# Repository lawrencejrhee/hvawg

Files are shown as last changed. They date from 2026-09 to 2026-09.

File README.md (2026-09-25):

# High Voltage Arbitrary Waveform Generator

This is the first draft iteration of a modular arbitrary waveform generator intended to generate possibly tens of separate ±100V 1MHz signals for small capacitive loads, e.g., electrostatic actuators or ion traps.

WARNING: THIS BOARD IS DANGEROUS. IT USES SOMEWHAT HIGH VOLTAGES AT SOMEWHAT HIGH POWER. DO NOT BUILD, TEST, OR USE WITHOUT BOTH CAUTION AND KNOWING WHAT YOU ARE DOING. No guarantees or warranty or support is provided, etc.

3D render of PCB

Specifications:
- serial data input at 3.3V or 5V up to maybe 100MHz, intended to be driven by FPGA
- 8-bit onboard DAC (with +/-1V output) (ENOB not measured but probably closer to 6 bits)
- amplifier with 100x gain gives outputs ±150V
- maximum output frequency is in the 100kHz range varying with load and voltage
- maximum designed load is tens of picofarads and megaohms of resistance
- up to four boards can be daisy-chained
- quiescent power consumption around 5 to 10W (b/c inefficient class A output stage)
- efficiency ≈1% (b/c inefficient class A output stage in open loop control)
- boards cost about $20 each and use only standard off-the-shelf parts

Measured frequency response:

(generated by feeding external signal into on-board amplifier bypassing DAC)

frequency response curve

## Circuit Design

This circuit was made with the following constraints in mind:
- This is primarily intended to drive small capacitive loads, on the order of tens of picofarads with maybe megaohms of resistance. Note that oscilloscope input impedances are also about this much.
- Arbitrary waveform outputs between -100V and +100V and up to 1MHz. Either of those constraints is easy; together they are nontrivial. The ADHV4702 opamp can reach those voltages but only up to about 20kHz, for example.
- In order to have multiple outputs, multiple boards should be able to be daisy chained together. The final design allows up to four boards to be daisy chained and driven off a single 4-wire serial connection (three signals plus GND), for an average of 0.75 input signals per board, to drive as many boards as possible off of a single FPGA or other controller.
- Low cost. If tens of these boards are required for an application, each one should individually be cheap. This resulted in, e.g., five separate power supply inputs. The final part cost per board is around $20. Note a 2-layer PCB was used to decrease manufacturing time for external reasons; switching a 4-layer PCB or better is probably a good idea to allow better EMI mitigation techniques.
- DAC accuracy was not a priority. The original application needed less than 6 bits of resolution.
- Mass production. The circuit should not rely on manually matched transistors for a carefully-balanced amplifier. Instead, the output uses current mirrors that are cheaply implemented with off-the-shelf silicon power MOSFETs and don't require closed loop control on the output (which is not easily achieved at 1MHz at those voltages due to transistor switching time). (There is still manual tuning of amplifier gain and bias in order to minimize cost and accuracy, but this only has to be done once per board.)
- Robustness. The output can probably survive a short-circuit (untested).

The amplifier looks something like the following:

frequency response curve

### Alternatives

Previous but insufficient approaches to similar problems include:
- Using a high-voltage op-amp, e.g., the ADHV4702 <https://www.analog.com/en/products/adhv4702-1.html>. This can achieve the +/-100V range but only up to a bit over 20kHz.
- Resonant circuits. Common in ion traps and particle accelerators, but only generate a single specific frequency.
- Discrete amplifiers of assorted topologies, e.g., <https://doi.org/10.1063/1.1988272> or <https://doi.org/10.1063/1.3622750> or <https://www.radiolocman.com/shem/schematics.html?di=637101>. Note also <https://www.falco-systems.com/High_voltage_amplifier_WMA-300.html>. Commonly used for piezoelectric actuator drives, ultrasound, MEMS, or ion traps. These amplifiers achieve the required voltage and frequency specifications but are expensive and/or complex and rely on obscure components.

### Power input

This board takes five power inputs (in addition to the GND connection, of course):
- +12V (1W)
- -12V (1W)
- +100V (5W)
- -100V (5W)
- 12V above the -100V negative rail (1W)

These should be turned on in the following order:
1. +12V
2. -12V
3. +100V
4. -100V
5. 12V above -100V rail

LEDs indicate when the three 12V power supplies are on.

The power supplies used for testing were Wanptek WPS series supplies (160V 2A and 30V 10A) from eBay.

The +/-100V high voltage supplies are used to drive the output and need to be capable of the full board power draw (potentially 10W each, depending on component selection and voltage output).

The +/-12V supplies are used to drive the DAC and intermediate amplifier opamps. These are not generated from the +/-100V because a linear regulator would be too lossy and a buck regulator would make the board significantly more complex and expensive.
Likewise, the low 12V supply is used to drive the output amplifier opamp, and is not generated from the other supplies for the same efficiency reason.

If more convenience is required, an external board can generate the 12V and 100V supplies however desired.

### DAC

The DAC circuit takes a serial input via the 74HC595 shift register and sends the output to a DAC0909 DAC chip.

The DAC is 8 bits. Four PCBs can be daisy-chained together (requiring 32 bits).

The DAC should theoretically operate up to about 100MHz, allowing four 8-bit daisy-chained boards to be updated at above 1MHz. This upper speed has not been tested yet and may be limited by inferior PCB routing.

The DAC protocol works (via the 74HC595) as follows:
- Input signals at 3.3V or 5V should both work.
- 4 pins are required (GND, store_clock, shift_clock, and serial_in).
- First, data is sent in via serial_in at each rising edge of the shift_clock.
- Next, when store_clock is brought high, the current state of the data is saved and sent to the DAC.

This should work with any 74HC595 code, e.g., many Arduino libraries.

### Level shifter

The level shifter circuit accepts an input +/-1V analog signal, translates this into a current, and sends the result to the negative high voltage rail, where it is converted back into an analog voltage to drive the output opamp.

The level shifter can be disconnected from the DAC via jumper JP3 in order to input an external analog signal (e.g., from a low-voltage waveform generator) for testing purposes.

Potentiometer RV1 controls the gain of the high voltage output and should be adjusted to give a 100x amplification.

NOTE: PCBs FABBED FROM PRE-2026-09-09 DESIGN FILES HAVE AN ERROR (see "Errata" below) where the source and drain of PMOS transistor Q3 are switched. If this is not fixed during assembly, when the high voltage low rail is turned on, significant current will flow through R17, which will burn out due to excessive power draw. The design files were corrected on 2026-09-09 (schematic pin mapping + copper reroute, DRC/ERC/netlist verified); boards fabbed from the corrected files take Q3 with straight legs. The exported gerbers under jlcpcb/ are generated from the V2 design revision, which includes this fix.

### High side monitor circuit

This subcircuit provides compensation such that the final high-voltage output is independent of the high voltage supply level (i.e., high voltage inputs of +50V, +100V, and +150V should not affect a 50Vpp output signal).

Potentiometer RV2 controls the DC bias of the output and should be adjusted to center the output at GND = 0V.

Resistor R12=110kohm dissipating up to 200mW was specifically chosen to minimize power draw while also maximizing the voltage/current at the input to opamp U8A (which has nonzero input offset current).

### Output amplifier

This circuit takes an input voltage signal near the negative rail (from the level shifter) and converts this into a current signal through Q1 and R21, which form a class-A amplifier to generate the final high-voltage output. The output voltage is determined by the voltage drop of R21 with the given current.

R21 and Q1, as a class-A amplifier, form a resistive divider between the high voltage power rails, and dissipate a large (10W) current even in their quiescent state in order to drive loads with reasonable accuracy. This means they generate significant heat.

R21 was chosen at 10k as a reasonable compromise between quiescent power draw and load drive ability. R21 can be replaced with a 5kohm power resistor to draw more current but double the output load capacity.

### Output

The final output from R21 and Q1 can be connected to any one of outputs 1 through 4 via jumpers JP8 through JP11.

Four daisy-chained boards can thus be attached to separate outputs.

## Assembly and Testing

### Part choice notes

- All SMD parts are from JLCPCB and specifically chosen from parts with reliable high stock.

- Hand-soldered components were added manually afterward (not through JLCPCB) to reduce order lead time.

### Manufacturing notes

These boards were designed in KiCad and ordered from JLCPCB with help from the excellent kicad-jlc-pcb tools plugin <https://github.com/bouni/kicad-jlcpcb-tools>.

### Assembly notes

Hand assembly of the through hole components takes about 20 minutes per board.

Boards fabbed from pre-2026-09-09 design files: be sure to bend the legs of the PMOS MOSFET (Q3) to switch its source and drain to fix a board error (see "Errata" section below). Boards fabbed from the corrected design files (2026-09-09 or later) install Q3 normally with straight legs — verify which revision a bare board is before assembly.

Header pins are ordered in lenths of 18 to reduce costs. These should be manually cut to size (or ordered in the right size to begin with).

The power resistor R21 needs spare wires soldered on to fit the PCB footprint. The resistor hangs off the edge of the board so it can be bolted to a heatsink. It's possible these spare wires increase EMI emissions. Future board iterations could switch to a TO-220 package power resistor, matching NMOS transistor Q1, which is also at the edge of the board for easy heatsink mounting.

V2 boards (the current design files) mount R21 on the board instead. It is a TO-220 power resistor (LTO050F10001JTE3) laid flat in a small bolt-on heatsink (Wakefield 272-AB), which is screwed to the board and tied to GND. Q1 still goes on a heatsink bar along the board edge. Its tab is at the output voltage, so it needs an insulating pad (Sil-Pad K-10) and a shoulder washer (Keystone 3049). V2 boards also change the connector pinouts, the trimpots (1kohm, wired as rheostats; RV1 now centers the output and RV2 sets the gain) and the power input (J9, a pluggable 8-pin terminal block). On V2 boards the 5kohm R21 option (see Output amplifier) would double R21's dissipation, beyond what the on-board heatsink is sized for. See BRINGUP-V2.md for assembly and bringup, and V2-SUMMARY.md for the full list of changes.

### Bringup notes

The notes below are for V1 boards. V2 boards use BRINGUP-V2.md.

After the board is assembled, the following bringup/test strategy seems to work well:

- Start with jumpers JP3, JP4, and JP6 disconnected. Connect one of JP8, JP9, JP10, JP11 to choose output.
- Test DAC. Apply +12V then -12V supply (if +12V but not -12V is applied too long, DAC may heat up). Confirm LEDs light up. Add DAC input signal. Use thermal camera to confirm no major hot spots (NE5532 opamps at 35°C, LEDs at 32°C, not much else).
- Confirm DAC output is good (TP2/JP3 via oscilloscope). Full scale output is around 2.8Vpp.
- Test high voltage monitor circuit. Attach +120V supply, confirm high voltage monitor output (TP3 via multimeter) is stable and good and in the 1 to 3V range. R12 should rise in temperature (maybe 36°C) due to its 200mW power dissipation.
- Turn off power supplies and add jumpers JP3, JP6.
- Test level shifter. Apply +12V, -12V, +120V, and -120V. Confirm temperatures good (no significant change from before).
- Confirm DAC and monitor outputs remain good.
- Confirm level shifter output is sine wave (measure JP4 oscilloscope with AC coupling).
- Turn supplies off again, add jumper JP4.
- Test final output stage. Turn supplies on, including +12V on negative rail this time (additional LED should come on).
- Confirm only thermal change is output resistor and MOSFET heating to maybe 60-80°C (if supplies are +/-120V).
- Confirm final board output (measured at TP5, output port, or resistor lead via DC-coupled multimeter) is expected signal. Might be DC shifted and cut off at high/low rail.
- Adjust RV2 to center output wave at 0V.
- Adjust RV1 to set gain to get about +/-100V output. Can set to +/-128V full-scale output so that a 1 bit input change results in 1V output change.

### SMD components (JLCPCB)

| Part no. | QTY | Cost | JLC type | Note | URL |
|---|-----|---|---|---|---|
| 74HC595D,118 | 1 | 0.10 | basic | shift register | https://jlcpcb.com/partdetail/Nexperia-74HC595D118/C5947 |
| DAC0808LCMX/NOPB  | 1 | 1.80 | extended | dac | https://jlcpcb.com/partdetail/TexasInstruments-DAC0808LCMXNOPB/C132006 |
| NE5532DR | 2 | 0.15 | basic | opamp | https://jlcpcb.com/partdetail/TexasInstruments-NE5532DR/C7426 |
| LM8261M5X/NOPB | 2 | 2.12 | extended | opamp | https://jlcpcb.com/partdetail/TexasInstruments-LM8261M5XNOPB/C7968 |
| L78M05ABDT-TR | 1 | 0.13 | basic | 5V regulator | https://jlcpcb.com/partdetail/Stmicroelectronics-L78M05ABDTTR/C58069 |
| KT-0603W | 3 | 0.01 | basic | white 0603 LED | https://jlcpcb.com/partdetail/Hubei_KentoElec-KT0603W/C2290 |
| RT0402BRE072K74L  |  12 | 0.02 | extended | 2.74kohm 0402 0.1% 62.5mW | https://jlcpcb.com/partdetail/Yageo-RT0402BRE072K74L/C705647 |
| WR20X750JTL | 1 | 0.02 | extended | 75ohm 2010 200V | https://jlcpcb.com/partdetail/Walsin_TechCorp-WR20X750JTL/C172257 |
| 1206W4F1004T5E | 4 | 0.01 | basic | 1Mohm 1206 200V 250mW | https://jlcpcb.com/partdetail/18615-1206W4F1004T5E/C17927 |
| UD2D4R7M0810 | 2 | 0.08 | extended | 4.7uF 200V SMD | https://jlcpcb.com/partdetail/HonorElec-UD2D4R7M0810/C88701 |
| CC0603KRX7R9BB104 |  12 | 0.01 | basic | 100nF 0603 50V | https://jlcpcb.com/partdetail/Yageo-CC0603KRX7R9BB104/C14663 |
| CL31A106KBHNNNE |  13 | 0.03 | basic | 10uF 1206 50V | https://jlcpcb.com/partdetail/14236-CL31A106KBHNNNE/C13585 |
| 2010W2J0114T4S | 1 | 0.01 | extended | 110kohm 2010 200V 500mW | https://jlcpcb.com/partdetail/21062-2010W2J0114T4S/C20351 |
| CRGP2512F22K | 1 | 0.41 | unknown  | 22kohm 2512 500V 2W (V2)  | https://www.lcsc.com/datasheet/C2076055.pdf |
| CL31B106KAHNNNE | 1 | 0.19 | extended | 10uF 1206 25V X7R (V2) | https://jlcpcb.com/partdetail/C14860 |

The last two rows are V2 parts: CRGP2512F22K is R30 and CL31B106KAHNNNE is C24. V2 boards also use D4, D5, R26-R29 and R31 (see the schematic). They take 12 of CL31A106KBHNNNE instead of 13, because C24 sits next to the R21 heatsink and must be the X7R part (rated to 125°C, while CL31A106KBHNNNE is X5R and rated to 85°C).

### Through-hole components (manually added afterward)

| Part no. | QTY | Cost  | Note | URL |
|---|-----|---|---|---|
| 3296Y-1-472LF  | 2 | $1.3  | 4.7kohm trimpot | https://www.digikey.com/en/products/detail/bourns-inc/3296Y-1-472LF/2536016 |
| IRF9610PBF | 1 | $1.1  | PMOS power FET | https://www.digikey.com/en/products/detail/vishay-siliconix/IRF9610PBF/811768 |
| IRF730PBF | 1 | $1.1  | NMOS power FET | https://www.digikey.com/en/products/detail/vishay-siliconix/IRF730PBF/811793 |
| QPC02SXGN-RC | 4 | $0.04 | jumper | https://www.digikey.com/en/products/detail/sullins-connector-solutions/QPC02SXGN-RC/2618262 |
| THS2510KJ | 1 | $2.5  | 10kohm power resistor | https://www.digikey.com/en/products/detail/te-connectivity-passive-product/THS2510KJ/2366983  |
| PREC018SABN-RC | 3 | $0.25 | 18-pin male header | https://www.digikey.com/en/products/detail/sullins-connector-solutions/PREC018SABN-RC/2775036 |
| PPPC181LGBN-RC | 3 | $0.82 | 18-pin female header  | https://www.digikey.com/en/products/detail/sullins-connector-solutions/PPPC181LGBN-RC/775951  |
| 3296Y-1-102LF  | 2 | - | 1kohm trimpot (V2) | https://www.bourns.com/docs/Product-Datasheets/3296.pdf |
| LTO050F10001JTE3 | 1 | $5.1  | 10kohm TO-220 (V2) | https://www.vishay.com/docs/50050/lto50.pdf |
| 272-AB | 1 | $0.79 | TO-220 heatsink (V2)  | https://www.digikey.com/en/products/detail/wakefield-vette/272-AB/345-1043-ND/340341 |
| 1844278 | 1 | $3.26 | J9 header (V2) | https://www.phoenixcontact.com/en-us/products/pcb-header-mc-15-8-g-35-1844278 |
| 1840421 | 1 | $9.32 | J9 plug (V2) | https://www.phoenixcontact.com/en-us/products/pcb-plug-mc-15-8-st-35-1840421 |

V2 boards use the 1kohm trimpots and LTO050F10001JTE3 instead of the 4.7kohm trimpots and THS2510KJ. They also need two M3 screws with washers and nuts plus non-silicone thermal compound (e.g., Wakefield 126) to mount R21 and its heatsink, and a Sil-Pad K-10 and Keystone 3049 shoulder washer for Q1 (details in BRINGUP-V2.md).

## Errata and Future Improvements

Board error (FIXED in design files 2026-09-09; still applies to boards fabbed before then):
- The PMOS transistor (Q3) source and drain pins are switched on the PCB. On boards fabbed from pre-fix files, this can be fixed when hand-soldering by bending the MOSFET legs to fit the right holes. Not doing this causes excessive current through R17, burning it out, with possible additional damage to RV1.
- Design-file fix (2026-09-09): the Q_PMOS_GDS symbol pin mapping for Q3 was corrected in hvawg.kicad_sch (S=pin 3 to the RV1/U6 network, D=pin 2 to levelshift_out, matching the physical IRF9610 G-D-S pinout), the corresponding pad nets were swapped and copper rerouted in hvawg.kicad_pcb (net "Net-(Q3-D)" renamed "Net-(Q3-S)", zones refilled). Verified: netlist shows Q3 pin 2 on levelshift_out / pin 3 on Net-(Q3-S); DRC and ERC reports are identical to pre-fix baseline (no new violations, 0 unconnected). Boards fabbed from these files install Q3 with straight legs. The exported gerbers and production zip under jlcpcb/ were regenerated for this fix on 2026-09-09 (drill files verified hole-identical; copper carries the corrected nets), and again from the V2 design revision from 2026-09-23 on (each time checked against the board: DRC clean, every drill-hole change accounted for). Regenerate them after any further board change. The BOM/CPL files have not been updated for the V2 parts; regenerate them with the kicad-jlcpcb-tools plugin.
- A safe first-power check for ANY board of unknown revision: set the negative-HV supply current limit to 2 mA and ramp toward -20 V. Reaching full voltage at under ~1 mA means Q3 is correct; pinning at the 2 mA limit with the rail collapsed means the swap is active (the 2 mA ceiling keeps R17 well within its power rating either way).

EMI issue:
- I suspect this board might sometimes generate nontrivial RF noise. Qualitative tests show unshielded wires on the output (or maybe even the wires connecting the through-hole power resistor) generate an undesired signal. Thus, be very careful with board use. Future board iterations should fix this issue by, e.g., more careful PCB trace design and changing the signal output connector to a shielded RF SMA connector or similar.

Improvements:
- The first iteration used a 25W chassis-mount power resistor, which worked fine without heatsinking but needed manual wiring to the PCB. To avoid the inconvenience of having a component not directly mounted to the PCB, future iterations might consider using a TO-220 package power resistor and heatsinking instead (e.g., AP836 10K J, https://www.digikey.com/en/products/detail/ohmite/AP836-10K-J/5878547 ).
- A 2-layer PCB was used to decrease manufacturing time for external reasons; switching a 4-layer PCB or better is probably a good idea to allow better EMI mitigation techniques.

## Images

### 3D render

3D render of PCB

### Assembled PCBs

Two assembled PCBs

### Thermal testing

Note the hottest parts of the circuit are the power resistor and MOSFET near the output, as expected.

Two assembled PCBs

### Frequency response testing

An external function generator was used to generate test waveforms by disconnecting the DAC via jumper JP3.

frequency response test setup

### Daisychain test

Two boards generating 200Vpp 1kHz waves

### PCB frame concept

Heatsinks, external wires, and control board not included. Note a large flat heatsink is easy to add along the output power resistors and MOSFETs.

PCB frame concept

### EMI Issue

Several-foot-long unshielded wires connected to the output and a capacitive load interfere with the signal generator. Note the waveform on the oscilloscope only shows half a sinusoid; the lower half was somehow blocked. The test was immediately stopped.

EMI discovery

Using a shielded cable reduced interference, but that's still not a perfect sinusoid on the oscilloscope. Recommendation: improve PCB to minimize external wires and other possible EMI sources and use a proper RF SMA connector for the output.

lower EMI with shielded cable

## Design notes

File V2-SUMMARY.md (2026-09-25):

# HVAWG V2: status, simulation results, decisions and remaining work

For: Yichen. Date: 2026-09-24. Status: the V2 design files and gerbers were committed on 2026-09-25 (61018b9).

TL;DR: Your items 1-9 are implemented and verified in the KiCad files, and the JLCPCB gerbers are regenerated from the final board. V2 also includes:
- a high-voltage safety revision (sections 2.6 and 2.7)
- R21 moved onto the board and laid flat in a Wakefield 272-AB heatsink (section 2.8)
- a re-layout: a plain 207 x 58.8mm rectangle with J9 in a small edge notch, new silkscreen, and U4B/U8B tied off (section 2.9)
- Sims 6 and 7: R21 parasitics and a coverage audit of every final value (section 2.10)
- the resolved decisions in section 3: R29 = 1Mohm, SMD test pads for TP9-TP12, J9 at 3.50mm, no BSS126, R21 flat, and R30 as a 2W 2512

LTSpice checks show the V2 values are correct as long as R19/R23 stay unpopulated.

Details below.

## 1. What was implemented

| # | Your item | Implementation | Status |
|-----|---|---|---|
| 1 | Fix the Q3 (IRF9610) S/D swap | Schematic pin map fixed, pad nets swapped, copper rerouted | Done, committed in 225dc5d |
| 2 | RV1 as a rheostat + 3.3k series | RV1 = 1k (wiper tied to pin 3), R26 = 3.3k | Done |
| 3 | RV2 as a rheostat + 820ohm series | RV2 = 1k (wiper tied to pin 3), R27 = 820 to GND | Done |
| 4 | Gate-source resistor + zener on the FETs | Q1: R28 100k + D4 BZT52C12 (K to G). Q3: R29 1Mohm (was 100k; changed per Sims 1/3/5) + D5 BZT52C12 (K to S) | Done |
| 5 | 10k between the divider tap and U8 | R30 in series with U8 pin 3. Only U8's input sits behind it. First 10k, now 22k 2W 2512 (sections 2.5, 2.7, 2.10) | Done, see the R30 finding in section 2.5 |
| 6 | Test points on the Q3/Q1 gates and sources and U7's rails | TP7/TP8 = Q3 G/S, TP9/TP10 = Q1 G/S, TP11/TP12 = -100+12V / -100V | Done. TP9-TP12 are SMD 1.5mm diameter pads 1.5-5.8mm from the pins they probe |
| 7 | TP6 after the series R; keep TP5 before it | TP5 on the amp side, TP6 on the new net output_post | Done |
| 8 | Empty pads for an R+C test load | R32 (1206) + C32 (first 0603, now 1206 pads; section 2.7), both DNP, from TP5 to GND | Done, see decision 4 in section 3 for where it attaches |
| 9 | Series output resistor on board | R31 = 4.7k (first 1206, now 2512 for voltage and fault margin; section 2.7) | Done |

The JP8-JP11 output selectors now sit on output_post, after R31.

Six existing nets were renamed automatically by KiCad because the new parts changed the alphabetical naming. Connectivity is unchanged:

| Old name | New name |
|---|---|
| Net-(Q1-G) | Net-(D4-K) |
| Net-(Q1-S) | Net-(D4-A) |
| Net-(Q3-G) | Net-(D5-A) |
| Net-(Q3-S) | Net-(D5-K) |
| Net-(JP10-A) | Net-(Q1-D) |
| Divider tap  | Net-(C14-Pad1) |

### Verification of the design files

The figures in this subsection and in section 1b are from that stage. The current board's check results are in section 2.8.

- Netlist: every item has the intended connectivity, and exactly 13 nets changed membership. All 260 of 260 pin-to-net assignments match between the schematic and the board.
- ERC: no new errors. There are actually two fewer: the unconnected RV1/RV2 pin 3 errors are gone because of the rheostat ties.
- DRC (after the connector fix in section 1b): 0 errors, 0 unconnected, 0 clearance/short errors, 0 silkscreen overlaps, 0 silkscreen over copper. What remains are pre-existing warnings only:
  - 8 silk_edge_clearance: R21/Q1 graphics, which intentionally hang past the board edge for heatsinking.
  - 37 lib_footprint_mismatch: the KiCad 9 library versions differ from the ones on the board. These were intentionally not "updated", to avoid changing pads on parts that work.
  - 29 footprint_symbol_mismatch: exclude-from-BOM flag differences.
  - For comparison, the original design had 5 errors and 91 warnings, and the first V2 version had 5 errors and 165 warnings.
- Gerbers: regenerated and installed in jlcpcb/.
  - Every drill-hole change is accounted for (PTH holes went from 125 to 132 overall). The V2 parts added 7 new Keystone test points (TP6-TP12). The connector fix moved connector pins and TP8 and changed some vias.
  - A second export matches the installed files byte-for-byte except timestamps.

### 1b. Connector spacing fix (the 5 DRC errors)

The original design had 5 courtyard-overlap errors: the daisy-chain and power connectors sat flush against each other. Since only V2 boards will be stacked, they were spread apart by the smallest amounts that clear them:

| Part | Move | Notes |
|---|---|---|
| J1-J4, J7, J8 | none | Daisy-chain pins unchanged |
| J5 + J6 (HV daisy-chain pair) | +1.27mm in x, both identical | Every mating pair still lines up exactly |
| J9 (bench power input) | +1.27mm in y | Pinout unchanged |
| J10 (GND pin) | +1.27mm in x | |
| TP8, R31 | +0.5mm / +0.25mm in x | Moved to make room |

- Assembly note: J3+J5 and J4+J6 used to form one continuous 8-pin row, and J7+J10 a 5-pin row. Each connector now needs its own header strip.
- HV clearances improved. The closest +HV to -HV copper went from 0.47mm to 0.84mm. All rerouted copper keeps at least 0.8mm between the HV rails and at least 0.5mm from HV to anything else.
- Every pad kept its net.
- The schematic is untouched.

## 2. Findings from the simulations

The netlists are in simulations/v2/ (the logs come from running them and are not committed). There is no LTSpice model for the IRF9610 or IRF730, so datasheet-based VDMOS approximations were used. The comparisons are more trustworthy than the absolute numbers. The LM8261 uses the vendor model, unchanged.

### 2.1 Your RV1/RV2 values are correct when R19/R23 are not fitted (Sim 1)

With the op-amps enforcing their virtual shorts:
- Centered gain = (R21 / R_src) x R_load / R_RV1
- Centering requires R_RV1 = K x R_bottom / (110k + R_bottom), where K = (R21 / R_src) x R_load

| Board | K | RV1 needed to center | Result with the V2 range (3.3-4.3kohm) |
|---|---|---|---|
| R19/R23 unfitted (as built) | 10k/75 x 2.7k = 360,000  | about 3.6kohm at R_bottom = 1.11k | Centers at ±50V and ±120V, gain about 90-120 |
| R19/R23 fitted | 10k/42.9 x 96.4 = 22,500 | about 225ohm | Cannot center. Output stuck near the + rail, gain about 5-7 |

- R19 and R23 must stay DNP.
- Note on BRINGUP-V2.md: an earlier draft's Phase 3 example (96.4/R_RV1, R_RV1 = 225ohm) described the fitted configuration. The current BRINGUP-V2.md uses the as-built numbers, 2.74k and about 3.65kohm. With the final values the usable gain range is about 85-110 (from the RV2 window in section 2.10 item 3).
- Output = 100 x V_DAC, independent of the rail voltage (the monitor compensation doing its job). The usable DAC swing is therefore about ±V_TP3, roughly ±0.5V at ±50V rails. A full-scale DAC (about ±1.4V) clips at both rails, which explains the clipped outputs seen on the bench at ±50V.

### 2.2 R29 = 100k breaks rail-independence (Sims 1, 3, 5), recommend 1Mohm

R29 carries V_SG / R29, about 18-38uA depending on Q3's threshold, around Q3. That current does not scale with the rail voltage, while Q3's current does (about 137uA at ±50V, about 332uA at ±120V). So a board trimmed at one rail voltage is off-center at the other.

Output offset after trimming at one rail voltage and then running at the other:

| R29 | Q3 Vth | Trimmed at ±120V, run at ±50V | Trimmed at ±50V, run at ±120V |
|---|---|---|---|
| 100k  | -2 / -3 / -4V | +3.6 / +5.8 / +7.9V | -8.7 / -14.0 / -19.1V |
| 1Mohm | -2 / -4V | +0.2 / +0.6V | -0.5 / -1.5V |

At 100k it also degrades the level shifter (Sim 3):

| Metric | V1 (no R29/D5) | R29 = 100k | R29 = 1Mohm (+ D5) |
|---|---|---|---|
| THD at ±50V | 2.2% | 5.3% | 2.65% |
| THD at ±120V | 1.3% | 2.2% | 1.55% |
| TP4 shift | - | -77mV (about +0.1V DAC-equivalent offset) | -7.7mV |
| Usable positive DAC swing at ±50V | - | -19% | - |

- 1Mohm still holds Q3 off. Worst-case IRF9610 gate leakage (about 100nA) x 1Mohm is about 0.1V, far below |Vth| = 2-4V.
- It's a value change only. Same 0402 footprint, so the gerbers are unaffected.
- With 1Mohm, the nominal RV2 setting (R_bottom about 1.11k) centers at both rail voltages (RV1 about 3.57k).

### 2.3 D4/D5 zeners, R28, and R31 (Sims 2 and 3): fine with the IRF730

- Output stage at 100kHz (IRF730 as fitted, and STW11NM80):
  - V2 costs 0.3% of swing at TP6 with a 10pF load, and 0.9% with 20pF.
  - It adds a +0.3V offset, which the trim removes. (This is sim-stage wording. In the V2 procedure, RV1 is re-trimmed live at the operating rail to center the output, and RV2 sets the gain; see BRINGUP-V2.md section 4.5.)
  - Stable, with no oscillation after a step.
  - The zeners never conduct (Q1 Vgs stays within 1.6-4.5V).
- Level shifter: D5 is harmless.
  - Bandwidth stays around 20MHz.
  - Phase margin improves from about 71° to 77°.
  - It speeds up recovery from clipping (it keeps U6 out of saturation).

### 2.4 BSS126 option: rejected (2026-09-24)

The BSS126 is not used. Its SOT-23 package (about 0.36W) can't dissipate the roughly 2.2W in Q1 at ±150V, and the real part is depletion-mode, which this circuit can't turn off. Q1 stays the IRF730. The sim findings below are kept for the record.

If the output FET is ever swapped to the BSS126 (the fast, low-capacitance option from earlier sims):
- The earlier "BSS126 + 1k gate stopper" setup has a hidden limit cycle of about 0.2Vpp at about 2.8MHz. It only shows up in step/zero-input runs, not in a 100kHz sine run.
- With V2's R31 (4.7k) added, it oscillates at 10-13Vpp (about 2.2MHz, self-starting).
- A stopper of about 3.3k brings the residual down to 0.4-0.6Vpp and still reaches about ±148V.
- The datasheet says the BSS126 is depletion-mode, while the sims used an enhancement-mode approximation. D4 would then fight its turn-off. This needs a proper model before committing to the BSS126.

The sims suggested adding a series gate resistor footprint between U7's output and Q1's gate: 0ohm for the IRF730, or about 3.3k for the BSS126. This was not on the original list and has not been added (see decision 3 in section 3).

### 2.5 U8 monitor protection (Sim 4): big improvement, one remaining gap

Current into U8's input pin (NE5532 absolute max ±10mA):

| Scenario | V1 (current boards) | V2 |
|---|---|---|
| Worst DC fault, at 150V | 1.35mA (7.4x margin) | 0.15mA (65x margin) |
| RV2 wiper open, powered | tap clamps at 12.6V, 1.25mA | tap 2.44V, 0mA |
| ±12V falling in 1-10ms with +HV still on | 13-120mA (the 10uF C15 dumps through U8's clamp diode) | at most 0.19mA |

- The last row matters for the boards we already have. Any fast ±12V shutdown with HV still up exceeds U8's input rating, and it is a plausible cause of the op-amp failures seen so far.
- NOTE: ON V1 BOARDS, STRICTLY FOLLOW THE SHUTDOWN ORDER. RAMP +HV TO 0 BEFORE TURNING OFF ±12V.
- Item 3 (rheostat tie + R27) handles the DC faults.
- Item 5 (R30) handles the power-down transient.
- Remaining gap: if the tap is shorted straight to +HV (for example, a probe slip), V2 still passes 13.7mA at 150V, and the 0402 R30 would dissipate about 1.9W and burn open.

The suggested fix was R30 = about 22k in 0805/1206 (6.2mA in that fault).
- Cost: about twice the offset from U8's input bias current (2.2mV typ, rising to about 4.5mV). This sim-stage note originally said the RV2 calibration trims it out. The current procedure treats it as a fixed drop at TP3 that does not scale with the rail, so RV1 is retrimmed at each rail setting (section 2.10 item 2, and BRINGUP-V2.md section 4.5 step 1).
- It changes the footprint, so the gerbers would need regenerating.
- Done: R30 is 22k. Sim 7 then showed that an 0805 would still dissipate 0.87-0.97W in this fault, so R30 is now a 2W 2512 (TE CRGP2512F22K; sections 2.7 and 2.10).

### 2.6 High-voltage safety audit and spacing fix (done 2026-09-23)

KiCad's DRC was not checking high-voltage spacing: the project had a single 0.2mm clearance for every net. A voltage-aware audit instead assigned each of the 54 nets its worst-case voltage at the ±150V design rails and measured every pair against IPC-2221B (bare pads A6, masked copper B4). The results:
- At ±50V (the current bench): 0 violations.
- At ±150V: 12 issues. 8 were fixed by copper edits, and the other 4 are fixed by the safety revision in section 2.7.
  - The +100V/GND spot went from 0.20mm to 0.66mm.
  - The GND pour now keeps 1.0mm from exposed HV pads (was 0.5mm).
  - Five traces were rerouted away from HV pads.
  - No parts moved, and no nets changed.
- New hvawg.kicad_dru rules file. KiCad's DRC now enforces voltage-domain clearances (HV vs LV, +HV vs -HV/output, output vs everything). The rules were tested and fire on the old board.
- Component stress audit: no part is over its rating in normal operation. The remaining physical concerns:
  - Q1 needs a heatsink above about ±125V (its tab is at the output voltage). This was the audit's first estimate. The current figures are about ±118V as the physical limit at 40°C ambient, and the bringup procedure requires Q1's bar above ±50V (section 2.8, BRINGUP-V2.md section 5).
  - Q3's tab sits at about -150V.
  - R21 dissipates up to 8.9W while the output clips at the negative rail.

### 2.7 Safety revision (approved 2026-09-23 by Lawrence, implemented and verified 2026-09-24)

Verification (figures from that stage; the current board's results are in section 2.8):
- DRC with the HV rules: 0 errors, 0 unconnected, and no remaining KNOWN_SHORTFALL exceptions (Q1/Q3/C32/TP12 are fixed at the source).
- Voltage-aware audit at ±150V: 0 violations and 0 edge failures. The tightest gap is 0.805mm against 0.8mm required, from the Q1 drain track to Q1 pin 1.
- Every pad matches the netlist, and every net change is intended.
- Gerbers regenerated. Every hole change was reconciled (PTH holes went from 132 to 146).

Where the build differs from the approved plan (needs confirmation):
- J9 is a 3.50mm pitch block (Phoenix MC 1,5/8-G-3,5), not 3.81mm. The 3.81mm body (31.9mm) doesn't fit between the J5 and J7 cable plugs (31.75mm gap). The 3.50mm part is the same family with the same rating and gives a 1.7mm gap between contacts, versus 2.0mm for 3.81mm and 0.84mm for the old header.
- The board outline grew. At first a 30.5 x 10.8mm tab on the top edge carried J9 (board 150 x 50.85mm, was 150 x 40mm). That is superseded and the tab is gone. The board is now a plain 207 x 58.8mm rectangle with J9 at the top edge between J5 and J7, in a 0.5mm edge notch (section 2.9). A mechanical check is still needed: computed from the Phoenix drawings, the J9 plug clears the J5/J7 cable plugs by about 1.9mm on each side, assuming 2.54mm pin housings centered on the pins. Verify this against the real cable plugs.
- Q1 tab warning: the front silkscreen has the short form "Q1 TAB=OUT +/-150V" (no room for the full text). The full "Q1 TAB = OUTPUT +/-150V - INSULATE" is on the back silkscreen.
- Parts moved to make room:
  - R24, R25, TP6, TP12, D3/R3, C26/C27 (+0.2mm).
  - J7/J8 now span x 182.68-197.92 (pins 1-4 unchanged; 5-7 added). J10 was deleted.
  - The old J9 header pads became vias.

The revision was approved because this is a very-high-voltage board and new boards will be stacked (connected by cables between the edge sockets).

WARNING: THE PINOUTS CHANGE, SO ALL V2 BENCH WIRING AND CABLES MUST FOLLOW THE NEW TABLE BELOW. V2 BOARDS DO NOT MATCH V1 WIRING.

Connector pinouts (option A: no two adjacent pins more than 150V apart):

| Connector | Old pinout | New pinout |
|---|---|---|
| J5 / J6 (HV daisy-chain, 4 pins) | 1 GND, 2 +100V, 3 -100+12V, 4 -100V | 1 +100V, 2 GND, 3 -100V, 4 -100+12V |
| J7 / J8 (output bus) | 1x04: OUT1 to OUT4 adjacent (up to 300V apart), plus J10 = GND | 1x07: 1 OUT1, 2 GND, 3 OUT2, 4 GND, 5 OUT3, 6 GND, 7 OUT4 (J10 removed; its GND is now in the bus) |
| J9 (bench power input) | 2.54mm header: 1 GND, 2 GND, 3 +12V, 4 -12V, 5 GND, 6 +100V, 7 -100+12V, 8 -100V | 3.50mm pluggable terminal block (option B; approved as 3.81mm, see above): 1 GND, 2 +12V, 3 -12V, 4 GND, 5 +100V, 6 GND, 7 -100V, 8 -100+12V. Pin 1 is the right-hand end. |

J3/J4 (±12V) are unchanged. The daisy-chain sockets stay in place; only the output-bus sockets get longer. The power-on order is unchanged.

Part and footprint changes:
- Q1 and Q3: HV variant of the TO-220 footprint with narrower pads. The gap between pads goes from 0.635mm to 0.99mm (1.55mm pads at 2.54mm pitch). The legs stay straight.
- R30: 10k 0402 changed to 22k. It was first an 0805, but Sim 7 showed the 0805 would overheat (0.87-0.97W) with the monitor tap shorted to +HV. It is now a 2W 2512, TE CRGP2512F22K (22k 1%, 500V, pulse-rated thick film; LCSC C2076055), which survives that fault at about half its rating.
- R31: 1206 changed to 2512 (1W), for output-fault robustness.
- C32 (DNP): 0603 changed to 1206 pads. If it's ever fitted, it must be rated at least 250V.
- TP12: moved in from the board edge.
- Silkscreen: HIGH VOLTAGE warnings near the HV connectors; "Q1 TAB=OUT +/-150V" at Q1 (front) and "Q1 TAB = OUTPUT +/-150V - INSULATE" (back); "TAB ~ -150V" at Q3. The full current silkscreen is listed in section 2.9.

Assembly and operation notes:
- Q1: its tab is the output (up to ±150V). Mount it alone on the right-edge bar with a Sil-Pad K-10 (rated at least 1kV) plus a Keystone 3049 nylon shoulder washer, and tie the bar to GND. Never leave the bar floating or at output potential. The bringup procedure requires the bar above ±50V (recommended at ±50V). Physically, Q1's centered dissipation needs it above about ±118V at 40°C ambient (section 2.8, BRINGUP-V2.md sections 3.6 and 5).
- R21: laid flat in its own GND-bonded heatsink, HS1 (section 2.8). There are no flying leads.
- Stacks at ±150V: plan for forced airflow, since each board dissipates 5-10W.
- Conformal coating is recommended for ±150V operation. Mask HS1 and its screws before coating.

### 2.8 R21 on the board, laid flat in its own heatsink (implemented and verified 2026-09-24)

The chassis-mount THS2510KJ on flying wires is replaced by an on-board Vishay LTO050F10001JTE3, a 10kohm TO-220 power resistor. It is the part on the BOM. The flat footprint is dimensioned for the LTO 50 only, so the earlier alternate (C&B/RESI TPAN0220F10K0K9) is dropped. Its ratings were checked against the datasheet (<https://www.vishay.com/docs/50050/lto50.pdf>):
- 500V working, versus 300V worst case across R21.
- 50W at 25°C case, 24W at 90°C, versus 8.9W worst case.
- Isolated ceramic back, 1500VRMS. Rth(j-c) 2.5°C/W; element maximum 150°C.

R21 first stood upright at the right edge (about 19.7mm tall) and shared Q1's heatsink bar. On 2026-09-24 it was laid flat (decision 7 in section 3).

- Mounting: R21 lies ceramic face down in the trough of a Wakefield 272-AB channel heatsink, reference HS1. This is the plain bolt-on version (Digi-Key 345-1043-ND), not 272-AB01/-02. HS1 is 44.45 x 36.83mm and 9.5mm tall, and it is bonded to GND. Sim 6 recommends grounding the metal that R21's element couples to (here the sink); tying it to +HV should behave the same. A floating sink would sit at an undefined potential next to ±150V copper, so HS1 must never be left floating.
- Placement: HS1's trough runs along x, left of Q1. The sink spans x 219.0-255.9, y 81.8-126.2. R21's hole is concentric with HS1 hole 1 at (232.5, 104.0); hole 2 is at (242.4, 104.0). R21's leads point left (-x) to two slotted pads at x 213.8:
  - pad 1 = output (Net-(Q1-D)), the upper pad at y 101.46
  - pad 2 = +100V, the lower pad at y 106.54
  - The pad gap is 2.48mm, against 0.8mm required at 300V.
- Board changes:
  - The right end is 57mm wider (section 2.9).
  - Q1 and its drive block (U7, D4, R15, R18, R22, R23, R28, C24, C25, TP9-TP12) moved 57.5mm right as a unit, so the gate/source loop is unchanged.
  - A masked F.Cu GND plate lies under the sink floor, stitched to the B.Cu GND pour by 12 tented holes. The footprint keeps all tracks and vias out from under the floor.
  - The long output run (Net-(Q1-D), F.Cu, 0.5mm) goes from R21's pad-1 junction up to y 88 and along it to Q1's drain via at (281.3, 96.3). It passes under HS1's upper fins, about 8mm from the floor plate. The B.Cu GND pour stays out of y 80-96.5 along it, to keep the output-node capacitance down (see "Output-node capacitance" below).
  - New footprints: Library:TO-220-2_Horizontal_LTO50 (R21) and Library:Heatsink_Wakefield_272-AB (HS1). HS1's schematic symbol is Mechanical:Heatsink_Pad_2Pin, with both pins on GND, and it is in the BOM.
- Lead forming: the LTO 50 datasheet offers no bend option, so the bend is borrowed from Vishay's LTO 100 option TB8. Its leads have the same 3.5mm shoulder and 0.6mm thickness:
  - straight for 4.2mm from the body
  - inner radius 1.2mm
  - 90° toward the ceramic side
  - outer lead face 6.0 ±0.5mm from the body
  - Form the leads in a jig, clamping each lead between the body and the bend.
- Slots: the plated slots are 1.5 x 3.0mm. They were lengthened from 1.5 x 2.8mm on 2026-09-24, because JLCPCB requires a plated slot to be at least twice as long as it is wide. The 2.6 x 4.2mm oval pads are unchanged, leaving 0.6mm of copper at the slot ends.
  - The slots let the 0.8 x 0.6mm lead move about ±1.1mm along the lead (±1.08mm nominal, about ±1.04mm at JLC's -0.08mm slot tolerance) and ±0.35mm across.
  - That travel covers the ±0.5mm bend check together with R21's own body tolerance (hole to the lead end of the body 13.0mm, from 16.2mm and 3.2mm, each ±0.3mm) and about 0.075mm of drill position: about ±0.66mm combined (RSS), about ±1.2mm worst case.
  - The worst case is covered by the M3 screw's clearance in R21's and the PCB's 3.2mm holes (about ±0.14mm each), which lets R21 shift slightly to suit its leads.
  - The slots meet JLC's rule exactly (the drill file gives 1.5011 x 3.0023mm, a ratio of 2.00). If JLC's DFM review still flags them, 1.5 x 3.1mm gives margin and leaves 0.55mm of copper at the slot ends.
- Hardware per board:
  - Hole 1 (through R21, the sink and the PCB): an M3x12 pan-head screw with a DIN 125 flat washer on R21's molded face.
  - Hole 2 (sink only): an M3x8 pan-head screw with a DIN 6797-J internal-tooth lock washer on the sink base. The teeth bite through the anodizing, and that is what bonds the sink to GND.
  - Under the board: a DIN 127 split washer and an M3 nut on each B.Cu GND ring. The nuts and screw tails stick out about 5-6mm below the board.
  - Non-silicone thermal compound (Wakefield 126) between R21's ceramic and the sink floor. No insulator is needed, because the ceramic back is isolated.
- Assembly order:
  1. Form the leads.
  2. Grease the ceramic and place R21.
  3. Screw down both holes at about 0.5-0.6Nm (estimate). The datasheet's mounting torque is about 1Nm (recommended, not a stated maximum). Use the lower figure because the FR4 is in the clamp stack.
  4. Solder last.
- Thermal envelope: these are estimates at 40°C ambient in open air, from the Wakefield catalog curve. A closed stack is worse.
  - No fan: every case up to about ±100V is fine, including sustained clipping (R21 about 3.9W). At ±150V without a fan, allow only centered sine and near-0V outputs (R21 element about 87°C, sink about 75°C), and keep any sustained DC output above about -50V. That keeps R21 at or below about 4W, the same as the accepted ±100V clipped case. In general the no-fan DC limit is +HV - 200V.
  - A DC output held lower at ±150V (R21 takes 8.4W at -140V, 8.9W clipped at the rail) needs at least 1m/s of airflow across HS1's fins. With 1m/s (about 200LFM, sink-to-air resistance about 5°C/W from the 272-AB curve) the sink stays at about 82-85°C and the R21 element at about 111-116°C at 8.4-9W, against the 150°C element limit. Without airflow the sink reaches about 107-113°C and the R21 element about 136-144°C (about 141-144°C at 9W; the catalog's table point runs about 5% hotter than its curve).
  - Headroom from the rail only prevents clipping; it does not reduce heating. An output kept 10V off the negative-rail clip (-140V) still puts 8.4W into R21. The driver's V_MAX is a clip-avoidance limit; the no-fan limit is a host-side DC limit near -50V (BRINGUP-V2.md section 4.5 step 6, and section 5).
  - The silkscreen marks the sink "HOT >100C" and "SINK = GND".
  - C24 (10uF 1206 on the floating 12V) sits about 7mm from the sink outline. The May JLC BOM part for the 10uF 1206 caps (C13585, CL31A106KBHNNNE; Samsung's "A" code is X5R) is rated to 85°C. The PCB next to a 107-113°C sink (no-fan near-rail case) can exceed that, so C24 is now an X7R (125°C) part: Samsung CL31B106KAHNNNE, 10uF ±10% 25V X7R (-55 to +125°C) 1206, LCSC C14860 (JLC extended part; JLC has no basic or preferred X7R 10uF 1206). 25V is twice the 12V floating rail. Like the X5R part it replaces, it gives less than 10uF at 12V bias, which is fine for this bulk decoupling. The schematic's C24 now carries the MPN and a Note with the LCSC number. Check its temperature during the section 5 soak in BRINGUP-V2.md.
- Q1 is now alone on the right-edge bar. The bar carries only Q1, at most 2.23W (centered output at ±150V; Sim 7), so it only needs to span board y 99-111 or so.
  - A bar of at most 10°C/W is recommended. With the IRF730's Rth(j-c) of 1.7°C/W plus about 0.5°C/W for the Sil-Pad, that puts Tj at about ambient + 27°C.
  - Up to 30°C/W still keeps Tj at or below 125°C at 40°C ambient.
  - This replaces the old spec of at most 3.5°C/W, which covered R21 plus Q1.
  - Q1 still needs a Sil-Pad K-10 plus a Keystone 3049 nylon shoulder washer, because its tab is live. Tie the bar to GND.
  - Bar height: the bar stands on the board's right edge, so it must not be taller than the clear space to the next board in a stack (the standoff length, at least 22mm; section 4), and it must not hang below the board, or it hits the neighboring board's bar. Its height is therefore limited by the spacing chosen for the stack.
  - Edge pull-in: the right board edge (x 283.0) sits 0.405mm inside the tab face of Q1's footprint model (F.Fab line at x 283.405), so a flat bar should touch the tab, not the PCB edge. At JLC's ±0.2mm routing tolerance about 0.2mm is left. Q1's pads stay 1.5mm from the edge.
  - Real parts vary. The footprint puts the tab back 3.15mm from the lead centerline, near the top of the Vishay TO-220 range (2.59-3.23mm, nominal about 2.9mm). A real IRF730's tab can therefore sit anywhere from about 0.16mm behind the edge to about 0.48mm proud, before routing tolerance. Measure Q1's lead-to-tab-back distance with calipers (the drawings are ±0.3mm). Clamp Q1 and its Sil-Pad to the bar before soldering Q1's leads. The play of the leads in their 1.1mm holes (about 0.1mm for a nominal lead, at most about 0.25mm; a rectangular lead is stopped by its corners) then lets the tab seat flat on the bar. Check with calipers on the first board that the bar touches the tab, not the PCB edge.
- Checks on the final board (custom HV rules loaded, zones refilled):
  - DRC: 0 errors, 0 unconnected, 0 silkscreen overlaps, 0 silkscreen over copper, and no exclusions. The warnings are 32 library-version mismatches, 4 silkscreen-past-edge items (Q1's outline at the heatsink edge, intentional) and 28 exclude-from-BOM parity items.
  - Voltage-aware audit at ±150V, including the board edge: 1273 pairs, 0 violations.
  - Every track bend is at least 135°.
  - ERC is unchanged.
  - The GND pour and floor plate stay at least 2.36mm from R21's pads, at least 3.1mm from the output copper added for the flat R21, and at least 4.0mm from the long output run.
  - The gerbers and production zip in jlcpcb/ were regenerated from this board and checked (section 4).
  - All of these checks were re-run after the last changes (R21's slots lengthened to 1.5 x 3.0mm; MPN and Note fields added to C24 and J9) with identical results, item for item. The netlist is unchanged node for node.
- Output-node capacitance (re-routed 2026-09-24): the output node now has 115.3mm of track (44.9mm before the flat R21).
  - The first flat layout ran the long output track 1mm wide at y 92.5, 3mm from the floor plate and the B.Cu pour. A separate check put its added copper at about 3.1pF. Together with R21's grounded case capacitance (about 3pF), that came out at +10.1% TP5 rise time at a 30pF load, just over Sim 6's 10% budget. (An earlier "+3% edge time" figure was wrong: it compared lumped copper with Sim 6's distributed case capacitance.)
  - The long run is now 0.5mm wide at y 88, with the B.Cu pour pulled back to y 80. By a 2-D field solve (the separate check's method, applied to every output-node segment), the node carries about 1.9pF more than the pre-flat board. The same method gives 2.8pF for the first flat layout.
  - The Sim 6 generator with R21's 3pF case grounded, plus the added copper lumped at TP5, gives these worst-edge changes against ideal:

    | Added copper                                 | 30pF load | 10pF load |
    |----------------------------------------------|-----------|-----------|
    | 1.9pF (field solve)                          | +5.7%     | +4.5%     |
    | 2.2pF (plus the check's 0.3pF method offset) | +6.5%     | +5.0%     |
    | 2.5pF (margin)                               | +7.8%     | +5.5%     |

    Sim 6's 10% budget is applied here to what the R21 change adds: R21's case plus the copper added over the pre-flat board, +5.7% worst at a 30pF load (first row). It does not count the output-node copper the board already had. Counting all of the output-node copper (about 4.2pF) plus R21's case against an ideal resistor, the rise at a 30pF load is about 13% slower (about 7% for the pre-flat board on the same basis).
  - R21's element-to-sink capacitance (about 3pF) is an estimate, the same as it was on the old grounded bar. Measure it on an LCR meter (section 4). With the 1.9pF of added copper, the 10% limit at a 30pF load is reached at about 6.5-7pF (5pF gives about +8%, 8pF about +11.5%). The Q1 tab on its grounded bar adds more (Sim 7 item 5). Measure the edges on the first board (section 4).
- Stack height (the stack spacing is a requirement for whoever builds the stack, not a board constraint; section 4):
  - At least 22mm clear between boards (about 23.5mm top-to-top), because the upright Q1 and Q3 stand up to 19.9mm, plus a 2mm margin. That was already true before this change.
  - HS1 (9.5mm) and R21 with its screw head (7.2mm) are well inside that. HS1's nuts and screw tails stick out about 5.7-6.0mm below the board, so the bottom board of a stack needs feet of at least 8mm.
  - Every THT lead must be trimmed to at most 2.5mm below the board.
- To verify on real parts:
  - the lead bend (6.0 ±0.5mm) with calipers
  - HS1 fin to GND under 1ohm
  - R21's element-to-back capacitance on an LCR meter, with both leads shorted to each other and measured to the sink or the ceramic back. No vendor publishes it. Sim 6 alone allows about 10-15pF, but with the added output copper the limit is about 6.5-7pF (see above).

### 2.9 Re-layout, J9 edge notch, silkscreen and U4B/U8B tie-offs (2026-09-24)

- Outline: a plain rectangle with 5mm corner radii and no tab, x 76.0-283.0, y 68.2-127.0, so 207.0 x 58.8mm.
  - The re-layout first made it 150 x 58.8mm: the top of the old J9 tab became the whole top edge, and the bottom edge moved down 8mm.
  - The flat R21 then widened the right end by 57mm.
- J9 edge notch: the top edge steps back 0.5mm (to y 68.70) over x 150.20-180.84, behind J9.
  - Why: Phoenix's mating drawing has the PCB edge flush with the header face. Right at that face the MC-ST plug's lower body already reaches below the board's underside (about 2.2mm below the PCB top, and about 3.4mm a little further out).
  - Without the notch, the board stuck out 0.30mm in front of the header face (y 68.50) and stopped the plug about 0.3mm short of seating.
  - With the notch, the edge is 0.20mm behind the header face. It stays at or behind the face even at JLC's ±0.2mm routing tolerance. The notch runs about 0.6mm past each end of the header body, and the 1mm +HV track behind J9 stays 0.70mm from the notched edge (the HV track-to-edge rule is 0.6mm).
- J9 plug: Phoenix MC 1,5/8-ST-3,5, order no. 1840421 (Mouser 651-1840421, Digi-Key 277-5715-ND, LCSC C3579977). It mates with the 1844278 header.
  - Wire it off the board with 600V-rated hookup wire (e.g. UL1015). Pin 7 carries two leads (-HV supply and floating 12V supply), crimped into one twin ferrule (e.g. Phoenix AI-TWIN 2x0,5-8 WH).
  - Never plug or unplug it live (Phoenix: not to be plugged or unplugged under voltage). It is held by friction only (about 32N).
  - Rating: the header sets it, 250V for overvoltage category II / pollution degree 2 (a lab bench). At ±150V rails no two neighboring pins are more than 150V apart, which is also within the 160V that LCSC lists for the plug. +HV (pin 5) and -HV (pin 7) are separated by the grounded pin 6.
  - WARNING: DO NOT EXCEED ±150V RAILS.
  - Wiring table and harness check: BRINGUP-V2.md section 1.5.
  - The schematic's J9 now carries the MPN (1844278) and a Note naming the mating plug 1840421 (bought separately), so a BOM generated from the schematic lists the header part number. J9's board footprint is excluded from the board BOM (one of the 28 parity items), so a board-based plugin BOM may leave J9 out. That is harmless, since J9 is hand-fitted.
- Mounting holes: H1 (81.0, 73.2), H2 (81.0, 122.0), H3 (278.0, 73.2) and H4 (278.0, 122.0).
  - They are M3, 5mm from both edges, in a 197.0 x 48.8mm pattern.
  - V1 used 140 x 30mm, so V2 boards no longer share standoff positions with V1.
  - They are not connected to GND.
- Connectors: J1/J3/J5/J7 sit on the top edge and J2/J4/J6/J8 on the bottom edge. Their x positions are unchanged, so each mating pair (J1/J2, J3/J4, J5/J6, J7/J8) still lines up. J9 sits between J5 and J7 on the top edge.
- Routing: the functional blocks were spread out for HV separation. Every track was re-made with 45° geometry: every bend is at least 135°, and branches join as 45° Y-junctions.
- Silkscreen (all text at least 1.0mm tall with at least a 0.16mm stroke):
  - "HV_AWG v2" (was "v1") at the top left, beside J1.
  - J9: pin numbers 1-8 with the net name under each pin. Pin 1 is the right-hand end: 1 GND, 2 +12V, 3 -12V, 4 GND, 5 Vhi, 6 GND, 7 Vlo, 8 Vlo+12.
  - Pin-name labels at every daisy-chain socket (new at J3-J6):
    - J1/J2: "GND ser_in/ser_out ser_clk store"
    - J3/J4: "GND GND +12V -12V"
    - J5/J6: "Vhi GND Vlo Vlo+12"
    - J7/J8: "1 G 2 G 3 G 4"
  - "HIGH VOLTAGE" beside J5, J6, J7, J8 and J9.
  - HS1: "HS1 / SINK = GND / HOT >100C" above the sink, and "SINK = GND" inside its outline, where it is visible before assembly. "HV" between R21's pads and the sink.
  - "Q1 TAB=OUT +/-150V" above Q1 (front), "Q1 TAB = OUTPUT +/-150V - INSULATE" on the back, and "TAB ~ -150V" at Q3.
  - "DC adjust" and "gain adjust" are now horizontal. "DC adjust" sits between RV2 (upper) and RV1 (lower), and "gain adjust" is below RV1.
- U4B/U8B tie-offs: the unused halves of both NE5532s are now grounded followers (pin 5, +IN, to GND; pin 7, OUT, tied to pin 6, -IN) instead of floating inputs. They are not in any signal path.
- R30 is now the 2512 at (162.2, 89.9), between RV2 and U8. C14 moved to (153.0, 88.5).

### 2.10 Sims 6 and 7 (2026-09-24)

Both are in simulations/v2/. Neither uses the cshunt option: it adds 1pF to every node, including the inside of the LM8261 macro-model, and it produced false limit cycles.

- Sim 6, R21 parasitics (sim6_README.md, sim6_results.json; 61 cases at ±150V):
  - No oscillation in any case: L from 0 to 5mH, element-to-housing capacitance from 0 to 100pF, housing grounded or floating.
  - With the housing grounded, element-to-housing capacitance up to about 15pF (10pF load) or 10pF (30pF load) keeps rise and fall within 10% of ideal.
  - Series inductance does not matter below about 0.5mH.
  - Ground the housing. Tying it to +HV should behave the same (by inspection, not simulated). A floating housing cuts the edge penalty about 4x, but it leaves metal at an undefined potential next to ±150V, so it is not recommended. HS1 is on GND.
- Sim 7, coverage audit (sim7_README.md, sim7_results.json; 196 cases): every final value in the signal and HV path is simulated and passes, at ±150V and ±50V.
  - sim7_README.md is up to date with the follow-ups below: R30 is the 22k 2512; the R30 bias drop lowers TP3; Sim 5's offsets are paired with the ±50V to ±120V change it covered; the realistic-Crss phase margin is about 20-47°, not the 50-59° once called pessimistic; and 38 cases, not 34, needed a second .op route.
  - The realistic-Crss re-check in item 4 is not in the repo (its Crss values were assumed, not read off the IRF730 curve).

Sim 7 findings:

1. R30 with the monitor tap shorted to +HV: U8 is protected (6.3-6.6mA), but R30 dissipates 0.87-0.97W. An 0805 would overheat in a sustained short and fail open (safe for U8), so R30 is now the 2W 2512.
2. Trim RV1 at the rail you will run. U8's input bias current flows through R30 and lowers TP3 by a fixed amount that does not scale with the rail: about 5mV with a typical NE5532 (0.2uA x 22k), 11-18mV with the Sim 7 model and at maximum bias. Trimmed at ±50V and run at ±150V, the output sits at -2.9 to -4.4V (-5.2V with a maximum-bias NE5532). For the pairing Sim 5 covered (±50V to ±120V), Sim 7 gives -2.0 to -3.1V against Sim 5's -0.5 to -1.5V (no R30), about 1.5V worse. The NE5532 model biases above the datasheet typical, so typical parts show somewhat less.
3. RV2 works only between about 0.2 and 0.5kohm. At either end of RV2 no RV1 setting can center the output. The bringup preset (0.29kohm) is inside the window.
4. Stability: stable with every load from 10pF to 1nF. A re-check with a realistic high-voltage IRF730 Crss gives less phase margin, about 20-47°. That is still stable, but a step can overshoot on the Q1 source current and ring at 2-3MHz for about 2us. On the bench, probe TP10 (Q1 source) and TP9 (gate) as well as TP5.
5. Q1 tab capacitance: Q1's tab on the grounded bar, through a Sil-Pad, adds roughly 20-40pF at TP5 (estimate). It was not simulated together with R21's case capacitance. Sim 6's grounded cases cover that size for stability, but it does slow the edges.

## 3. Decisions (resolved 2026-09-24 by Lawrence unless noted)

| # | Question | Decision |
|-----|---|---|
| 1 | R29: 100k to 1Mohm? | Yes, 1Mohm (done). Restores rail-independent centering and cuts level-shifter distortion (Sims 1, 3, 5). BOM value only. |
| 2 | R30: 10k 0402 to something larger? | Done: 22k. First 0805 (safety revision), now a 2W 2512, TE CRGP2512F22K (LCSC C2076055), after Sim 7's tap-short finding (section 2.10). |
| 3 | Gate-resistor footprint for Q1 (for a BSS126 swap)? | No. The BSS126 is rejected: its SOT-23 package (about 0.36W) can't take the roughly 2.2W in Q1 at ±150V, and it is depletion-mode, so this circuit can't turn it off. Q1 stays the IRF730. |
| 4 | Test load R32/C32 at TP5 or TP6? | Keep at TP5. It is the only on-board way to load the amplifier stage directly during bringup. The TP6 side can be loaded externally through the output connectors. |
| 5 | TP9-TP12 placement? | Switched to SMD test pads (done): TP9 Q1 gate 5.8mm, TP10 Q1 source 4.5mm, TP11 U7 V+ 1.5mm, TP12 U7 V- 5.1mm (pad edge to pin, final board). They are bare copper pads, so they are excluded from the BOM in both the schematic and the board. |
| 6 | J9 at 3.50mm pitch instead of 3.81mm? | Yes, 3.50mm (header Phoenix 1844278). Same family and rating; 3.81mm doesn't fit. The mating plug is the Phoenix MC 1,5/8-ST-3,5, order no. 1840421. |
| 7 | R21: how to mount the LTO 50? | Lay it flat (2026-09-24), and keep the LTO050F10001JTE3 that is on the BOM. Ceramic face down in a Wakefield 272-AB bonded to GND (section 2.8). |

## 4. Remaining work before ordering

- [x] Gerbers and production zip regenerated from the final board (2026-09-24) and checked.
  - Edge.Cuts is x 76-283, y 68.2-127 (207 x 58.8mm), with the J9 notch.
  - Drill hits went from 139 to 156, and every change is accounted for. HS1 adds two 3.2mm holes and 12 x 0.3mm stitching holes. R21's two round holes became two plated slots, now 1.5 x 3.0mm. Vias went from 49 to 52.
  - The zip holds the same 14 files as jlcpcb/gerber/.
  - Regenerated again after the output-run re-route (section 2.8). Only the two copper layers changed. The drill files (156 hits), masks, silkscreen, paste and Edge.Cuts are identical apart from their dates.
  - Regenerated again after R21's plated slots were lengthened from 1.5 x 2.8mm to 1.5 x 3.0mm (JLCPCB's capabilities page: a plated slot must be at least twice as long as it is wide). Only the PTH drill file (the two slot lines) and its drill map changed. All 156 holes reconcile one to one with the board, and the copper, mask, silkscreen, paste and Edge.Cuts layers are identical apart from their dates.
  - Regenerate them again after any further board change.
- [ ] Regenerate the JLC BOM/CPL with the kicad-jlcpcb-tools plugin (manual step).
  - The CSVs in jlcpcb/production_files/ date from May 2026 and do not include the V2 parts.
  - Assign LCSC part numbers for the new assembled parts (D4, D5, R26-R31). R30 = C2076055.
  - C24 changes part: use the X7R 125°C Samsung CL31B106KAHNNNE, LCSC C14860 (section 2.8), not the X5R C13585 that the May BOM assigns to it. The other 10uF 1206 caps stay C13585.
  - The schematic's C24 and J9 now carry MPN and Note fields (C24: the LCSC number; J9: header 1844278, plug 1840421 bought separately).
  - J9 is hand-fitted, like HS1. HS1 is in the KiCad BOM (it is a part to buy) but it is fitted by hand, so give it no LCSC number or exclude it in the plugin.
- [x] Silkscreen cleanup: done (0 overlaps, 0 labels over copper).
- [x] The 5 connector courtyard DRC errors: fixed (section 1b).
- [x] HV spacing: fixed (sections 2.6 and 2.7). The voltage-aware audit is at 0 violations at ±150V, and the HV rules are enforced in DRC.
- [ ] Mechanical check of J9 with the real plug and the real J5/J7 cable plugs. The computed side clearance is about 1.9mm. (J9 at 3.50mm is decided, and the tab is gone.)
- Stack spacing: a requirement for building a stack, not a board constraint. The spacing is set by the standoffs and can be chosen later. Requirements:
  - At least 22mm clear between boards (about 23.5mm top-to-top), for example 25mm M3 standoffs, because the upright Q1 and Q3 stand up to 19.9mm (Vishay TO-220 drawing maximum) and need a 2mm margin. This assumes Q1 is held to its bar by a clip; a screw through Q1's tab needs roughly 25-27mm top-to-top. This was already true before the R21 change (the old 20mm pitch left only 18.4mm).
  - Every THT lead trimmed to at most 2.5mm below the board. Untrimmed Q1/Q3 leads reach about 8mm down, up to 9.5mm. At 23.5mm top-to-top they come within 1mm of the Q1/Q3 bodies on the board below with nominal parts, and touch them with maximum-tolerance parts.
  - Feet of at least 8mm under the bottom board, because HS1's nuts and screw tails stick out about 5.7-6mm.
  - The Q1 bar no taller than the clear space between boards (and not hanging below its board), so its height is limited by the spacing chosen.
- [ ] Airflow at ±150V. Without a fan, allow only centered sine or near-0V outputs at ±150V and keep any sustained DC output above about -50V (R21 at or below about 4W, the same as the accepted ±100V clipped case; section 2.8). Anything lower, including an output held near the negative rail, needs at least 1m/s across every HS1. Headroom from the rail only prevents clipping; it does not reduce heating, so a 10V clamp from the rail is not a substitute for the fan.
- [x] R21's Note field (schematic and board) now states the full rule: at least 1m/s across HS1 for any sustained DC output below about -50V at ±150V (in general below +HV - 200V), and no fan for sine or near-0V outputs. Done 2026-09-24. It is text only. Re-checked after the edit: DRC with rules gives 0 errors, 0 unconnected and the same warnings item for item; ERC and the netlist are identical; regenerated gerbers are identical to the installed set apart from dates.
- [ ] First-board checks for the flat R21:
  - HS1 fin to GND under 1ohm.
  - R21's element-to-back capacitance on an LCR meter. The 3pF used so far is an estimate; with the added output copper the 10% edge limit at a 30pF load is about 6.5-7pF.
  - Thermocouple the sink and the R21 top with the output clipped at ±50V (about 1W), to calibrate the thermal estimates.
  - Measure the TP5 and TP6 10-90% edges for a -100V to +100V output step and compare them with Sim 6's ideal (1.25 / 1.39us rise / fall at a 10pF load; 1.50 / 1.90us at 30pF). The 10% budget was applied to what the R21 change adds (+5.7% worst at 30pF; section 2.8). Against an ideal resistor, all of the output-node copper (about 4.2pF) plus R21's case slows the edges by about 5% (rise) to 8% (fall) at 10pF, and by up to about 13% (rise) at 30pF. The pre-flat board's figure was about 7% at 30pF. The Q1 bar adds more (Sim 7 item 5).
  - Probe TP10 and TP9 for ringing after a step (BRINGUP-V2.md section 4.4 step 14). Q1's -HV return from R22 to the bulk capacitor C27 grew from about 14mm to about 73mm, and the output node now runs about 70mm further to Q1's drain. The extra 60-70nH is about 1ohm at 2-3MHz, small next to R22 (75ohm) and R21 (10k), so it is judged minor, but those are the nodes where it would show.
- [x] Hand-solder BOM (README) updated for V2: J9 header 1844278 and plug 1840421, HS1 272-AB and its hardware, R21 laid flat, R30 2512, 1k trimpots. J7/J8 take 7-position sockets and J10 is gone. The V2 cable pinouts are in section 2.7 and BRINGUP-V2.md section 6.
- [x] Pre-existing HV spacing issue (previously listed, now fixed; the coordinates are from the board before the re-layout). At (154.75, 82.32), a +100V trace was only 0.20mm from a GND trace. That is 100-150V across 0.2mm, below the IPC-2221 guideline (at least 0.4mm with solder mask), and it was inherited from the original layout. The other sub-0.5mm spots the spacing check reported are between nets within a few volts of each other near the -HV rail (U7/D4/R17 area), which is fine.
- [x] Check the new via at (214.94, 105.30), which sat against U7 pin 4 (possible solder wicking). Resolved: the re-layout removed it, and no via touches a U7 pad on the final board.
- [x] Update the README's hand-solder BOM (it listed 4.7k trimpots; V2 uses 1k): done.

## 5. Notes for the boards we already have (V1)

Bench trim procedure, corrected by Sim 1:
1. Set RV2's bottom leg to about 1.1kohm, so TP3 is about 0.5V at ±50V.
2. Start RV1 at its maximum. The output idles near +11V, which is safe.
3. With the DAC held at midscale, turn RV1 down until TP5 reads 0V. That lands around 3.65kohm (rule of thumb: RV1 is about 7.3kohm x V_TP3).

Do not preset RV1 to 1kohm. That pins the output at the negative rail with about 1W in R21.

Other notes:
- At ±50V rails, keep the DAC within about ±0.5V (about 35% of full scale). The output is 100 x V_DAC.
- The output FET fitted per the README BOM is the IRF730. The schematic's pot values (3k/1k) were stale; the physical pots are 4.7k.

## Files

- BRINGUP-V2.md: staged bringup for V2 boards, updated with the corrected presets.
- BRINGUP-V1-BOARDS.md: bringup notes for the V1 boards (fabbed before the V2 revision).
- simulations/v2/:
  - Sim 1: v2_dc_levelshift_output.cir
  - Sim 2: sim2_classA_*
  - Sim 3: sim3_levelshift*
  - Sim 4: sim4_monitor_*
  - Sim 5: sim5_*
  - Sim 6 (R21 parasitics): sim6_README.md, sim6_results.json, sim6_*
  - Sim 7 (coverage audit): sim7_README.md, sim7_results.json, sim7_*

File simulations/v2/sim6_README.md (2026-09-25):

# Sim 6: R21 Parasitics at ±150V

This sim checks how R21's parasitics affect the V2 output stage at ±150V.

## Question

R21 (the 10kohm pull-up from +HV to the Q1 drain at TP5) is laid flat on the V2 board. One candidate part was a V1-style 25W aluminum-housed wirewound with its housing grounded. Could that part's series inductance, element-to-housing capacitance or self-capacitance slow the output edges or make the stage oscillate?

## Short answer

- No oscillation in any case. 61 cases were run, from L = 0 to 5mH and Ccase = 0 to 100pF, with the housing grounded or floating, Cpar 0 to 3pF, and Cload 10 or 30pF.
- The speed cost comes from the element-to-housing capacitance when the housing is grounded. Rise and fall stay within 10% of ideal up to about 15pF (Cload 10pF) or about 10pF (Cload 30pF).
- Series inductance is harmless up to about 0.5mH. Everything in the 0 to 200uH target range stays within 3.3%.
- Grounding the housing is fine for stability. Whether it is fine for speed depends on the part's real Ccase, which should be measured.

## Files

All files for this sim are in this folder and start with `sim6_`.

Kept in the repo:
- `sim6_run.py`: generates the netlists and runs them in LTSpice.
- `sim6_report.py`: computes the changes against the ideal case at the same Cload, applies the pass criteria, writes a summary into `sim6_results.json` and prints the tables below. It reads only `sim6_results.json`, so the tables can be reprinted without rerunning LTSpice.
- `sim6_results.json`: all results.
- `sim6_validate_sim2.cir`: the Sim 2 rebuild used as a transcription check (see Setup). `python sim6_run.py validate` rewrites it.
- `sim6_README.md`: this file.

Generated by `sim6_run.py` and not kept in the repo (git-ignored):
- the per-case netlists and logs, `sim6_L*_tran.cir`/`.log` and `sim6_L*_loop.cir`/`.log`
- `sim6_validate_sim2.log`
- `sim6_progress.txt`

All .log files in this folder are git-ignored. The other logs mentioned here, such as `sim2_classA_v2_irf730.log`, come from running the matching .cir file in LTSpice. To regenerate the Sim 6 files, run the scripts (see Rerun).

## Setup

- Stage: the same topology as `sim2_classA_v2_irf730.cir` (VAR=3). U7 LM8261 on a floating 12V rail, Rg1 1ohm into the IRF730 approximation, R28 100k and D4 BZT52C12 for gate protection (Cz 45pF), R31 4.7k to TP6, and a 10Mohm scope plus Cload at TP6. The models are copied verbatim from Sim 2.
- Board values, checked against `hvawg.kicad_sch`:
  - R21 10k, R22 75ohm (Sim 2 used 50ohm, so this is a change), R31 4.7k, R28 100k, D4 BZT52C12, Q1 IRF730.
  - R18 1Mohm from gate to -HV is added (it is a board part).
  - Rails are ±150V, each with 1ohm source resistance plus C26/C27 4.7uF (1ohm ESR).
  - The `cshunt=1e-12` option is removed. It adds 1pF from every node to ground, which would have put about 9 to 19pF of "Ccase" into the ladder even in the ideal case.
  - The U7 input is an ideal source referenced to -HV, as in Sim 2.
- Transcription check: `sim6_validate_sim2.cir` rebuilds Sim 2 (VAR=3, Cload 10pF, Cz 45pF) with this generator. It reproduces step 4 of `sim2_classA_v2_irf730.log` exactly: TP5 pp 278.641, TP6 pp 278.220, max 141.695, min -136.946.
- R21 model: 10kohm total, built as 5 T-sections. Each section is 1k + L/10, then a middle node, then 1k + L/10. Ccase/5 runs from each middle node to the housing node, and Cpar runs end to end from +HV to TP5. The housing is either grounded (node 0) or floating (1Gohm to +HV and 1Gohm to GND). When L = 0 the inductors are left out, so there are no 0H parts.
- One combined transient per case (640us, 5ns max step, gear), with 5ns input edges:
  - (a) 0 to 60us: 100kHz sine sized for ±140V DC-equivalent at TP5, measured over 20 to 60us.
  - (b) Large step: -100V to +100V at 90us and back at 140us. Measured: 10-90% rise and fall at TP5 and TP6, overshoot, settling to 1%, and ringing (hysteresis zero-crossings).
  - (c) Zero input: 0V from 190us, with a 200us window (240 to 440us) checked for pp and spectrum. Then a +50mV input step (about -6.7V out) and back.
  - (d) DC at -140V (520us) and +140V (580us), checked for pp and R21 power.
- A separate loop-gain AC run per case: Middlebrook double injection with the loop broken between the U7 output and Rg1, evaluated at TP5 = +140, 0 and -140V.
- Metrics are computed with numpy from the .raw files, which are then deleted. The .meas values in the .log files are a cross-check: pp and power agree to 1e-12. The rise and fall .meas use fixed ±80V levels, so they differ from the numpy 10/90% values by at most 2%.
- The transient and loop netlists include a `.nodeset` initial guess. In the transients it changes the results by at most 1e-4 relative (checked against earlier runs of 57 cases without it). Without it, the loop netlists' DC operating point takes about 100s.
- Each netlist runs as its own LTSpice process, with a 240s timeout and a 60s CPU-idle hang watchdog, and only its own process tree is killed.

Pass criteria:
- Timing: the 10-90% rise and fall times at TP5 and TP6 are within 10% of ideal (in either direction).
- Overshoot: the TP5 large-step overshoot is at most 5 percentage points above ideal.
- Stability: TP5 pp is under 50mV in every flat window, and every edge settles to 1% before the next event.

## Ideal R21 baseline (Cload 10pF)

| Measurement | Result |
|---|---|
| Rise / fall at TP5 (10-90%) | 1.250 / 1.389us |
| Rise / fall at TP6 (10-90%) | 1.253 / 1.396us |
| Rise overshoot | 3.7% |
| Settling to 1% (rise / fall) | 2.7 / 3.0us |
| 100kHz sine at TP5 | 260.8Vpp (+131.5 / -129.3V) |
| 100kHz sine at TP6 | 260.5Vpp |
| Zero-input pp at TP5 | 29uV |
| Loop phase margin at TP5 = +140 / 0 / -140V | 79.7 / 76.9 / 83.0° |
| Loop crossover at the same three points | 1.7 to 2.0MHz |
| R21 power, DC | 2.267W at -0.58V, 8.442W at -140.59V |

The power figures match (150 - V)^2/10k (2.27W and 8.44W). They are the same in every case, because the parasitics carry no DC current.

With Cload 30pF the ideal case gives rise / fall of 1.495 / 1.904us at TP5, and a TP6 sine of 245.6Vpp.

### Why the edges behave as they do

The stage is a current-mode stage, and on the rising edge Q1 briefly cuts off (Vgs dips to about 0.6V). For that interval TP5 is pulled up passively by R21 into the drain node. The drain node's effective capacitance is about 105pF (IRF730 Coss and Crss, plus R31 and Cload), so the time constant is about 1us.

A grounded housing adds roughly Ccase/3 to that node. It also adds a slow distributed-RC tail just below the +100V knee where Q1 re-engages. The 10/90% rise metric is sensitive to that knee, which is why the rise jumps from 60pF to 100pF.

A floating housing only moves charge between internal nodes, so it adds roughly Ccase/12, about 4x less.

## Results: grounded housing, Cload 10pF, full L x Ccase grid (Cpar 0)

Each cell gives the change in TP5 rise / fall against ideal. TP6 tracks TP5 to within 0.7 percentage points (see `sim6_results.json`).

| L \ Ccase | 0 | 10pF | 30pF | 60pF | 100pF |
|---|---|---|---|---|---|
| 0 | ideal | +3.1 / +5.3% | +9.2 / +16.1% | +18.7 / +32.8% | +54.3 / +55.7% |
| 1uH | -0.0 / -0.0% | +3.0 / +5.2% | +9.2 / +16.1% | +18.7 / +32.8% | +54.3 / +55.7% |
| 10uH | -0.1 / -0.2% | +3.0 / +5.1% | +9.2 / +15.9% | +18.6 / +32.7% | +54.1 / +55.5% |
| 50uH | -0.5 / -0.8% | +2.6 / +4.5% | +8.8 / +15.3% | +18.2 / +32.0% | +53.2 / +54.9% |
| 200uH | -1.9 / -3.3% | +1.2 / +2.0% | +7.4 / +12.9% | +16.9 / +29.7% | +49.7 / +52.7% |

- 100kHz sine at TP5: down 1.8V at 10pF, 5.5V at 30pF, 11.9V at 60pF and 21.2V (-8%) at 100pF (L = 0). L = 200uH gives +1.1V.
- Loop: the worst phase margin in the grid is 67.4° (200uH / 100pF, at 0V), against 76.9° for ideal. Ccase moves the loop crossover from 2.0 to 2.5MHz through Cgd.
- Stability: the zero-input pp is 29 to 35uV in every case. There is no ringing on any edge, and the small step shows no overshoot.

Only the columns with Ccase up to 10pF pass. In the 30pF column the fall edge is more than 10% slow on every row.

## Results: spot checks (change against ideal at the same Cload)

| Case | TP5 rise / fall change | TP6 sine pp change | Worst PM | Pass |
|---|---|---|---|---|
| Floating, L0 C30p | +2.2 / +3.8% | -1.3V | 76.9° | yes |
| Floating, L50u C60p | +4.0 / +6.9% | -2.3V | 76.5° | yes |
| Floating, L200u C30p | +0.4 / +0.6% | -0.2V | 77.1° | yes |
| Floating, L200u C100p | +5.6 / +9.8% | -3.3V | 75.5° | yes (marginal) |
| Floating, L0 C100p | +7.5 / +13.0% | -4.5V | 75.5° | no |
| Floating, L200u C100p, Cpar 3p | +8.4 / +14.5% | -5.0V | 75.6° | no |
| Cpar 1p (L0 or L200u, C0) | -0.9 to +1.6% | ±0.5V | 77.0° or more | yes |
| Cpar 3p (L0 or L200u, C0) | +0.9 to +4.7% | -0.5 to -1.6V | 77.1° or more | yes |
| Cpar 1p / 3p on grounded C100p corners | +52 to +61% | about -21 to -23V  | 67.5° or more | no (Ccase dominates) |
| Cload 30p: L200u C0 | -1.6 / -2.3% | +1.2V | 70.3° | yes |
| Cload 30p: grounded C100p (L0 / L200u / +Cpar 3p) | +66 to +71 / +37 to +41% | -21 to -23V | 63.3° (lowest overall) | no |
| Cload 30p: floating L200u C100p | +16.0 / +6.9% | -3.7V | 70.0° | no |

## Results: extensions (grounded housing)

These cases find where each limit actually falls.

| Case | TP5 rise / fall change | TP5 overshoot, rise / fall | Ringing | Pass |
|---|---|---|---|---|
| L0 C15p (Cload 10p) | +4.6 / +7.9% | 1.0 / 0% | none | yes |
| L0 C20p (Cload 10p) | +6.1 / +10.6% | 0.1 / 0% | none | no |
| L200u C20p (Cload 10p) | +4.3 / +7.4% | 1.2 / 0% | none | yes |
| L0 C5p / C10p (Cload 30p) | +1.6 / +1.8%, then +7.2 / +3.7% | 0 | none | yes |
| L0 C15p (Cload 30p) | +12.9 / +5.6% | 0 | none | no |
| L500u C0 | -4.7 / -8.5% | 6.5 / 0% (peak 112.5V) | none | yes |
| L500u C30p | +4.5 / +7.8% | 1.0 / 0% | none | yes |
| L1m C0 | -9.6 / -18.1% | 9.4 / 0% (peak 118V) | none | no |
| L1m C30p | -0.3 / -1.5% | 4.0 / 0% | none | yes (L and C partly cancel) |
| L2m C0 | -18.6 / -37.7% | 15.5 / 0.2% | 0.21MHz | no |
| L5m C0 | -32.6 / -55.6% | 34.9 / 17.7% (TP5 reaches 169V, above +HV; sine peaks at 152V) | 0.2MHz, including the small step (23% overshoot) | no |

For the mH-level cases, the ringing is L resonating with the drain-node capacitance. It is passive and decays in every case. The loop phase margin actually rises with L (83 to 86° at 5mH).

## Conclusion

- Oscillation or limit cycles: none, in all 61 cases.
  - Zero-input pp at TP5 is at most 35uV, and gate pp is 31uV.
  - Every flat window is under 1mV. The largest, 0.81mV, is the tail of the -140V to +140V step.
  - Every edge settles, and no edge rings in the MHz range.
  - Loop phase margin is at least 63° everywhere.
  - The phase reaches -180° below 300MHz at only 18 of 183 operating points, and at those the gain margin is at least 28dB.
  - R21's parasitics are therefore not a stability risk to this loop. They load the drain, which reaches the loop only through Cgd.
- Range that stays within 10% of ideal on rise and fall, with no oscillation:
  - Grounded housing, Cload 10pF: Ccase up to 15pF (the 10% crossing is about 19pF, and the fall edge is the limiting one) with L up to 0.5mH.
  - Grounded housing, Cload 30pF: Ccase up to 10pF (the rise crosses 10% at about 12pF).
  - Floating housing: Ccase up to about 60pF passes (simulated at 50uH; L up to 50uH changes the edges by under 1%). 100pF fails at L = 0 (+13% fall) and is marginal at 200uH.
  - Cpar up to 3pF is fine (at most 4.7%).
- Maximum inductance: about 0.5mH. Series inductance speeds the edges up and adds overshoot. It fails at 1mH (-18% fall, 9.4% overshoot), and from 2mH it rings at about 0.2MHz. All of the 0 to 200uH target range is harmless (at most 3.3%, overshoot +1.1 points).
- Maximum case capacitance with the housing grounded: about 15pF (10pF if Cload can be 30pF).
- Is grounding the housing acceptable? Yes for stability and power. For speed, only if the part's element-to-housing capacitance is at most about 15pF.
  - At 30pF, a grounded housing costs 9 to 16% in edge time and 5.5V of 100kHz swing.
  - At 100pF it costs about 55% and 21V, but it is still stable.
  - Floating the housing cuts that penalty about 4x, but leaves a metal housing at an undefined potential next to ±150V circuitry, so it is not recommended.
  - Tying the housing to +HV instead of GND should behave the same as grounding, because C26 makes +HV an AC ground. This is by inspection; it was not simulated.
  - Next step: measure the real part's lead-to-housing capacitance, with both leads shorted, on an LCR meter at 100kHz to 1MHz. Wirewound inductance for a 10kohm part (tens to hundreds of uH) is not a concern.

See V2-SUMMARY.md section 2.8 for how this budget applies to the final board layout.

## Runs

- 61 cases x 2 netlists = 122 runs, all ok, with 0 timeouts and 0 measurement failures in the final data (no .meas FAIL, no numpy metric errors).
  - The cases are the 25-point grid, 5 floating, 9 Cpar and 6 Cload 30pF spot checks, and 16 extension cases.
  - There is also 1 validation run (ok).
  - LTSpice time: about 713s for the transients and 382s for the loop runs.
- In the parallel sweep, the 4 L=1uH, Ccase>0 transients timed out. Run one at a time, the same netlists finish in about 5s. Each LTSpice process is multithreaded, so running several at once, or next to other LTSpice jobs, can push cases past the 240s timeout. Rerun any case that times out, one at a time.

## Caveats

- The IRF730 is an approximate VDMOS model from the datasheet, so absolute edge times depend on its Coss and Crss. The changes against ideal are the robust result.
- The U7 input is ideal. On the board it comes from Q3 into R17 2.7k.
- The R21 ladder is a 5-section model of a distributed winding.
- No temperature effects or R21 tolerance are modeled.

## Rerun

Run the following from this folder. Use --jobs=1 if other LTSpice jobs are running.

```
python sim6_run.py validate
python sim6_run.py all --jobs=1
python sim6_report.py
```

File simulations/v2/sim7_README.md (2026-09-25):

# Sim 7: Simulation Coverage of the Final V2 Circuit

This sim checks that every final V2 value is covered by a passing simulation.

## Question

Is every final V2 value in the signal and HV path (hvawg.kicad_sch as of 2026-09-24) covered by a passing simulation? Sims 1 to 5 ran before several values changed (R30 10k to 22k, R29 to 1Mohm, R22 50 to 75ohm in Sim 2), and none of them simulated the whole chain.

## Short answer

- Yes. Every final value in the signal and HV path is simulated and passes, at ±150V and, where the bringup uses them, ±50V (and ±120V for centering).
- Three findings need attention. None of them calls for a value change; finding 1 changed R30's package.
  - Finding 1: R30 = 22k in a tap-to-+HV short. U8 is protected (6.3 to 6.6mA, below its 10mA absolute maximum), but R30 dissipates 0.87 to 0.97W. The 0805 first planned for R30 would overheat in a sustained short (it would fail open, which is safe for U8). R30 is therefore a 2W 2512, TE CRGP2512F22K (22k 1%, 500V, pulse-rated thick film; LCSC C2076055), which takes this fault at about half its rating.
  - Finding 2: changing rails without re-trimming costs more than Sim 5 said. R30's 22k carries U8's input bias current, which lowers TP3 by a fixed amount that does not scale with the rail. That is about 5mV with a typical NE5532 (0.2uA x 22k), and 11 to 18mV with the NE5532 model and at maximum bias. A board trimmed at ±50V and run at ±150V sits at -2.9 to -4.4V (TP5 at midscale), and down to -5.2V with a max-bias NE5532. For the pairing Sim 5 covered (±50V to ±120V), Sim 7 gives -2.0 to -3.1V against Sim 5's -0.5 to -1.5V (ideal U8, no R30), about 1.5V worse. The NE5532 model biases at about 0.46 to 0.5uA, above the datasheet typical of 0.2uA, so typical parts show less. Trim RV1 at the rail you will use.
  - Finding 3: RV2 has a usable window of about 0.2 to 0.5kohm. At its ends (0 or 1kohm) no RV1 setting in 3.3 to 4.3kohm can center the output. The bringup setting of about 0.29kohm is inside the window.
- The output stage is stable with the final values (R22 75ohm, R18, C24/C25). With the IRF730 model's own Crss (about 52pF, nearly flat out to 150 to 280V) the phase margin is 66 to 79° for CL 10 to 100pF at TP6, and 50 to 59° with a 20pF Crss floor. There is no oscillation or limit cycle, including with a 1nF load.
  - Those margins are not a worst case. A real IRF730's Crss falls well below 20pF at high VDS. A separate check with a realistic Crss (about 22, 12 and 7pF) gives about 20 to 47°. The stage is still stable, but a step can overshoot on the Q1 source current (about 30% at the lowest Crss) and ring at 2 to 3MHz for about 2us; TP5 itself shows no overshoot. On the bench, probe TP10 (Q1 source) and TP9 (gate) as well as TP5. That check is not in the repo, and its Crss values were assumed, not read off the datasheet curve.
  - The out and osc groups of Sim 7 did show limit cycles. They are an artifact of the cshunt=1e-12 option inherited from Sim 2 (see "The cshunt artifact" in section 2).

## Files

Kept in the repo:
- the netlist templates, `sim7_*.cir` and `sim7_ls_common.inc` (listed in section 4)
- `sim7_run.py`: the runner
- `sim7_report.py`: prints the tables in this file from `sim7_results.json`. When the logs in `sim7_runs/` exist it re-reads them first; `--save` writes the re-read values back to the JSON.
- `sim7_show.py`: prints selected results from `sim7_results.json` (`python sim7_show.py <substring> [keys...]`)
- `sim7_results.json`: all results
- `sim7_README.md`: this file

Generated by `sim7_run.py` and not kept in the repo (git-ignored):
- `sim7_runs/`, with the per-case netlists and logs
- `sim7_progress.txt`

The Sim 7 logs are all in `sim7_runs/`. To regenerate them, run `sim7_run.py` (see Rerun in section 4). The .log files in this folder itself are git-ignored too, but they belong to the other sims, not to Sim 7.

## 1. Final values vs what each sim used

The final values come from `kicad-cli sch export netlist` of the current schematic. The only change since the first snapshot of this audit is the U4B/U8B tie-offs: pins 5/6/7 are now wired as grounded followers. No values changed. "Sims 1 to 5" means the files listed in V2-SUMMARY.md.

| Part | Final schematic | Sims 1 to 5 | Sim 7 | Covered? |
|---|---|---|---|---|
| U3 DAC0808, R4+R5 (JP1 open) | Iref = 5V/5.4k = 0.926mA | Ideal V_DAC source (Sims 1, 3, 5) | Ideal current sink code/256 x Iref into R11. dac_out = +1.252V (code 0) to -1.238V (code 255) | Yes (ideal DAC) |
| R7, R8, R9, R10 (JP2 bridged), U4A NE5532 | 1.25V reference buffer | Not modeled | Modeled (NE5532.MOD) | Yes |
| R11 | 2.7k | 2.7k (1, 3, 5) | 2.7k | Yes |
| U6 LM8261, Q3 IRF9610 | as drawn | Yes (Vto -2/-3/-4 in Sim 5) | Yes, Vto -2/-3/-4 | Yes |
| R26 + RV1 (rheostat) | 3.3k + 0 to 1k = 3.3 to 4.3k | Swept (1, 5); 3.6k fixed (3) | Ramped to both ends and trimmed (3.42 to 4.24k) | Yes |
| R29 | 1Mohm | 100k (1, 3); 1M only in 5 and sim3_levelshift_isolate  | 1M everywhere (100k repro run as a check) | Yes |
| D5 | BZT52C12 | Yes | Yes | Yes |
| R17 / R19 | 2.7k / DNP | 2.7k; R19 fitted only in Sim 1 case B (cannot center)  | 2.7k / absent | Yes |
| R12 | 110k | Yes | Yes | Yes |
| R27 + RV2 (rheostat) | 820 + 0 to 1k | x2 = 0/290/500/1000 (1); 290/500 (5); nominal/open (4) | x2 = 0/290/500/1000 in the full chain | Yes |
| C14, C15 | 100nF, 10uF | Sim 4 | Sim 4 copy + chain | Yes |
| R30 | 22k, 2W 2512 (TE CRGP2512F22K; an 0805 when these sims ran) | 10k (Sim 4); absent (1, 5: ideal U8) | 22k (faults, power-down, chain); 10k as reference | Yes |
| U8A | NE5532 | Ideal buffer (1, 5); clamp model (4) | NE5532.MOD in the chain (+0.3uA extra-bias corner) and the Sim 4 clamp model | Yes |
| U7 LM8261, Q1 IRF730 | as drawn | Yes | Yes (Crss floor 50pF, and 20pF for sensitivity) | Yes |
| R21 | 10k, Vishay LTO 50 (LTO050F10001JTE3) laid flat in the grounded HS1 heatsink | 10k | 10k ideal; parasitics = Sim 6 | Yes |
| R22 / R23 | 75ohm / DNP | 75 (1, 5, 6); 50 (Sim 2) | 75 (50 as a comparison) | Yes |
| R28, D4 | 100k, BZT52C12 (Cz 45pF; 100pF checked) | Yes | Yes | Yes |
| R18 | 1Mohm gate to -HV | Sims 1, 5, 6; not Sim 2 | Yes | Yes |
| R31 | 4.7k (2512) | Yes | Yes (V1-like 1ohm as a comparison) | Yes |
| R32 / C32 | DNP | absent | absent | n/a (test-load pads) |
| C24, C25, R15 | 10uF, 100nF, 1M (floating rail) | Not modeled (ideal floating rail, Sims 1 to 6) | Yes | Yes |
| C26, C27 | 4.7uF HV bulk | Sim 6 only | Yes (0.5ohm ESR) | Yes |
| Load at TP6 (JP8-JP11 to J7) | cable plus scope | 10/20pF (2), 10/30pF (6) | 10, 22, 47, 100pF, and 1nF | Yes |

## 2. New results (all at the final values)

### Monitor

These are copies of Sim 4 with R30 = 22k. The 10k rerun gives Sim 4's numbers.

| Fault at +HV = 150V | U8 input, 10k | U8 input, 22k | P(R30), 22k |
|---|---|---|---|
| Normal / RV2 wiper open, powered | 0 / 0mA | 0 / 0mA | 0 |
| ±12V off, HV on (DC) | 0.09 / 0.16mA | 0.05 / 0.08mA | under 0.1mW |
| Bottom leg open (R30 only) | 1.24mA | 1.13mA | 28mW |
| Tap shorted to +HV | 13.8 to 14.2mA (over the 10mA abs max)  | 6.3 to 6.6mA | 0.87 to 0.97W, 146V across it |
| ±12V collapsing in 1/10/100ms (C15 dump) | at most 0.19mA (bottom leg open: 2.3mA) | at most 0.09mA (bottom leg open: 1.6mA) | under 0.06W |

### Level shifter

These are copies of Sim 3 with R29 = 1M and an RV1 total of 3.6k.

- Loop: phase margin is 70.1 to 71.9° at DAC -1.24/0/+1.25V, at both ±50V and ±150V (77.6° with R29 = 100k). Crossover is 14MHz, and the -3dB bandwidth is 22 to 26MHz.
- ±20mV steps: overshoot is at most 4.3%, with no residual ringing.
- 100kHz DAC sine:
  - ±150V, full DAC range ±1.24V: gain 0.75, THD 1.25%. Q3 never cuts off (Iq3 68 to 757uA).
  - ±50V, ±0.45V: THD 4.9%.
  - At ±50V, a full-scale ±1.24V input clips (58%), as Sim 1 predicted.

### Output stage alone

These start from sim2_classA, with R22 75, R18, C24/C25/R15 and C26/C27. Step runs use trapezoidal integration, and sine runs use gear as in Sim 2.

| CL at TP6 | Phase margin, 150V (TP5 = +130 / 0 / -130V) | PM, 50V | 50mV step (TP5 about 6.7V) | Zero-input TP5 pp | 100kHz sine at TP6, 150V (THD) |
|---|---|---|---|---|---|
| 10pF | 77.3 / 76.9 / 79.4° | 77.5° | no overshoot; TP5 tail at most 1uV pp at 80 to 100us | 0 | 278.6Vpp (2.96%) |
| 22pF | 72.4 / 72.2 / 75.5° | 72.8° | no overshoot; tail at most 1uV pp | 0 | 270.7Vpp (2.92%) |
| 47pF | 68.5 / 68.4 / 72.5° | 69.0° | no overshoot; tail at most 1uV pp | 0 | 248.7Vpp (2.80%) |
| 100pF | 66.3 / 66.3 / 70.9° | 66.9° | no overshoot (monotonic, still 1 to 1.6% short at 8us); tail at most 1.1uV pp | 0 | 196.9Vpp (2.28%) |
| 1nF (abuse) | 64.8° | - | slow RC settling only (time constant about 15us), no ringing | 0 | - |

- Crossover is 1.8 to 2.4MHz, consistent with Sim 6 (77° at 10pF).
- Crss floor of 20pF instead of 50pF: phase margin is 59 / 53 / 50° at 22 / 47 / 100pF, with no ringing. This is not a pessimistic bound: with a realistic high-VDS Crss the margin is about 20 to 47° (see the short answer).
- R22 = 50ohm (Sim 2's value) at 100pF: phase margin 61.5°. So R22 = 75ohm is slightly better.
- At ±50V the stage reaches 90.4Vpp at 10pF, with THD 7.5%.
- Q1 gate-source voltage stays at 1.7 to 3.7V. The D4 zener current is at most 42uA, which is just its junction capacitance.

The cshunt artifact:
- The copies of the Sim 2 netlists keep `.options cshunt=1e-12`. LTSpice adds that 1pF to every node, including the internal nodes of the LM8261 macro-model, whose only explicit capacitor is its 8pF Miller cap.
- With it, the U7 loop falls to a phase margin of -11 to +25° at about 1.1MHz.
- The step runs then show a sustained 0.14 to 0.56Vpp limit cycle at TP5 for CL of 33pF and up.
- With the 20pF Crss floor as well, they show a 27 to 30Vpp self-oscillation at 2.2MHz (groups out and osc).
- Removing only that option (group nocs, results above) restores 66 to 79° and removes every limit cycle.
- The full-chain transients and Sim 6 never used cshunt, and they agree with nocs.
- Conclusion: the with-cshunt results double-count parasitics in a vendor-fitted macro-model. They are kept only as a record.
- As a cheap bench check at bringup, look at TP5 at zero input and after a small DAC step with the real cable on, and check for 1 to 3MHz ringing at TP10 and TP9 as well as TP5.

### Full chain

This is new: the DAC path, U4A, U8A with R30 = 22k, U6/Q3 with R29 = 1M, and U7/Q1 with R22 = 75.

"Trim" is a servo on the RV1 total at midscale, which mimics the bench trim. "Fixed" means RV1 is left at the value trimmed on another rail. The x2 column is the RV2 setting.

| Rail | RV2 x2 | RV1 total to center | TP5 at RV1 = 4.3k / 3.3k | Gain (V/V) | Code 0 / 255 | TP3 |
|---|---|---|---|---|---|---|
| ±150 | 290 | 3545 to 3562 (Vth -4 to -2) | +26.0 / -11.5V | 101 | +126.5 / -125.5V | 1.487V |
| ±150 | 500 | 4215 to 4235 | +2.6 / -42.0V | 85 | +106 / -106V | 1.767V |
| ±150 | 0 / 1000  | 2621 / 5815 (outside 3.3 to 4.3k) | +30.8 at 3.3k / -52.8 at 4.3k | 137 / 62 | - | 1.10 / 2.43V |
| ±120 | 290 / 500 | 3532 to 3553 / 4202 to 4227 | +21.1 / -8.8V (x290) | 101 / 85 | +119.2 / -118.2 (x290: both clip); ±106 (x500) | 1.187V |
| ±50  | 290 / 500 | 3444 to 3494 / 4111 to 4171 | +9.6 / -2.6V (x290) | 103 / 87 | ±49.3 (clip) | 0.488V |
| ±50  | 0 / 1000  | 2537 / 5730 (outside) | - | 142 / 63 | - | - |

- Linearity: code 32/224 gives +94.9 / -94.9V at ±150V.
- Worst stresses:
  - Q1 gate-source voltage is at most 3.64V at ±150V.
  - When the output clips at the negative rail (±50V and ±120V) it reaches 11.2V, and D4 carries at most 0.2mA.
  - D5 carries at most 0.35mA forward while Q3 is cut off at ±50V.
  - Q1 dissipates 2.23W at midscale at ±150V.
  - R21 dissipates 7.6W at code 255 (TP5 = -125V).

Rail change without re-trim (TP5 at midscale):

| Trimmed at | Run at | x2 = 290 (Vth -2 / -3 / -4) | x2 = 500 | R30 = 10k (x290, Vth -3) | U8 bias 0.8uA (x290, Vth -3) |
|---|---|---|---|---|---|
| ±150 | ±50 | +0.94 / +1.19 / +1.43V | +0.76 to +1.24V | +0.78V | +1.66V |
| ±150 | ±120 | +0.29 / +0.36 / +0.43V | +0.23 to +0.38V | - | - |
| ±50 | ±120 | -2.03 / -2.55 / -3.07V | -1.62 to -2.66V | - | - |
| ±50 | ±150 | -2.90 / -3.65 / -4.39V | -2.32 to -3.80V | -2.38V | -5.16V |

Dynamics (RV1 fixed at the trimmed value, x2 = 290):
- Zero input: TP5 pp is 0.3uV at ±150V and 1.7mV at ±50V. The 1.7mV is a slow drift after the rail ramp, not oscillation.
- A +5-code step gives -4.94V at TP5 with no overshoot, at both 22pF and 100pF.
- A full-range 100kHz DAC sine at ±150V reaches 226Vpp at TP6 (THD 0.99%) at 22pF, and 163Vpp (0.81%) at 100pF.
- At ±50V, a ±45-code sine reaches 81.7Vpp.
- Neither zener conducts (at most 14uA).

## 3. What is still not simulated, and why it does not matter

- U4B and U8B tie-offs (grounded followers). These op-amp halves are not in any signal path. They only draw quiescent current.
- DAC0808 internals (C8 100nF COMPEN, R6, output compliance and glitches) and U1/U2 (7805, 74HC595). The DAC is modeled as an ideal current sink. This path is unchanged from V1, which produces correct waveforms on the bench, and no V2 value is involved.
- Supply decoupling C1 to C13, C20 to C23, C28 to C31 and the bleeders R24/R25. The sims use stiff sources with 1ohm series resistance, so these parts have no effect on the signal path.
- LED indicators D1 to D3 and R1 to R3. They are off the signal path. R3/D3 load the external floating 12V supply by about 4mA.
- R32/C32 test load (DNP). Its values are chosen at bringup and are not part of the design. R19/R23 must stay DNP (Sim 1).
- R21 parasitics (the flat LTO 50 in HS1): see Sim 6. The output-node copper added by the flat layout is covered in V2-SUMMARY.md section 2.8.
- Thermal behavior (Q1, R21, heatsink): not a circuit simulation; see V2-SUMMARY.md section 2.8.
- Model limits. Q1 and Q3 use datasheet VDMOS approximations; the Crss floor and Vth spread were varied. The LM8261 and NE5532 use their vendor macro-models.

## 4. Method and runs

Templates. These are copies of the Sim 2/3/4 netlists; the originals are untouched.
- `sim7_out_sine.cir`, `sim7_out_step.cir`, `sim7_out_loop.cir`: the output stage.
- `sim7_ls_common.inc` with `sim7_ls_ac.cir`, `sim7_ls_step.cir`, `sim7_ls_sine.cir`: the level shifter.
- `sim7_mon_fault.cir`, `sim7_mon_powerdown.cir`: the monitor.
- `sim7_chain_dc.cir`, `sim7_chain_tran.cir`: the new full-chain netlists.

Loop-gain break: the out_loop netlists break the loop with a voltage injection between the Q1 source (low-Z) and U7 -IN (high-Z). The phase of V(src)/V(fb) where its magnitude is 1 is the phase margin.

Runner: `sim7_run.py` generates each case into `sim7_runs/` and runs every netlist as its own `LTspice -b` process.
- Each process has a 240s hard timeout and a 60s no-CPU watchdog, and only its own process tree is killed.
- Logs are checked for freshness and decoded from UTF-16.
- The DC .op search is retried through documented options only (noopiter, gminsteps=0, srcstepmethod=1), or through an HV homotopy (the .op is solved at ±150V and the rails are then ramped).
- Every case is flagged OP FAILED if the .op is skipped.
- Results go into `sim7_results.json`.

Final data: 196 cases, 196 ok, 0 timeouts, 0 unexpected .meas failures.
- The failures that do appear are fring/t_set WHEN-measures that fail because there is no ringing, or because the edge is already inside the band.
- 38 cases needed a second .op route: 30 used the HV homotopy and 8 were no-nodeset AC runs.
- Cases can time out when LTSpice runs next to another LTSpice batch (the four 150V sine runs did while Sim 6 was running). They pass when rerun.
- The runner also has an osc2 group (in-loop compensation, with cshunt). It was dropped once the cshunt artifact was found and is not in `sim7_results.json`.

Groups in `sim7_results.json`:
- mon: 4
- out: 37 (with cshunt)
- osc: 28 (with cshunt)
- nocs: 50 (without cshunt)
- ls: 17
- chain1/chain2: 54
- ctran: 6

### Rerun

Run the following from this folder. chain2 and ctran need chain1 to have run first. With no arguments `sim7_run.py` runs every group, including osc2.

```
python sim7_run.py mon out osc nocs ls chain1 chain2 ctran
python sim7_report.py
```

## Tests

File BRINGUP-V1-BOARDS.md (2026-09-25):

These are the bringup notes for the V1 boards (A-D, fabbed before the V2 revision). For V2 boards use BRINGUP-V2.md.

The rest of this file is the older bringup procedure, kept as it was. The "v2" in its title is the second version of the procedure, not the V2 board. Some of it is now out of date: V2 J9 is no longer on a tab (it sits in an edge notch), and the gerbers in jlcpcb/ have been regenerated since.

# Bringup Procedure v2 (draft)

Updated staged bringup for the HVAWG board. Supersedes the README "Bringup notes"
for careful/first-article bringup. Key differences from v1: no floating opamp
inputs, staged HV ramps, much tighter current limits, and a defined shutdown
order.

## Quick reference at ±50 V rails (current lab setup)

The procedure below is written for the ±120 V design rails. Current bringup
runs at **±50 V** (E3612A = +HV, E3641A = −HV, triple-output = ±12 V with its
⊥/COM terminal as board GND, floating 12 V on the −100+12V pin: V1 J9 pin 7, V2 J9 pin 8). Scaled expectations:

| Quantity | ±120 V (as written) | ±50 V (current setup) |
|---|---|---|
| TP3 (RV2 = 1.11 kΩ) | ~1.20 V | ~0.50 V |
| TP3 (max possible, RV2 = 4.7 kΩ) | ~4.9 V | ~2.05 V |
| Centered R21 current | 12 mA | 5 mA |
| Initial HV current limit (Phase 4) | 25 mA | ~10 mA |
| Full-scale AC current limit | 35–40 mA | ~15–20 mA |
| Max output swing | ~±118 V | ~±49 V |

### ⚠️ J9 PINOUT DEPENDS ON THE BOARD REVISION — CHECK WHICH BOARD YOU HAVE

**V1 boards (A–D, fabbed before the V2 safety revision)** have a 2.54 mm
8-pin header J9. Count from the square pad:

| V1 J9 pin | 1 | 2 | 3 | 4 | 5 | 6 | 7 | 8 |
|---|---|---|---|---|---|---|---|---|
| Net | GND | GND | +12V | −12V | GND | +100V (+HV) | −100+12V (floating) | −100V (−HV) |

**V2 boards (safety revision, 2026-09-23)** have a 3.50 mm pluggable
terminal block J9 on the tab at the top edge. **The pin order is DIFFERENT.**
Pin numbers are printed on the silkscreen:

| V2 J9 pin | 1 | 2 | 3 | 4 | 5 | 6 | 7 | 8 |
|---|---|---|---|---|---|---|---|---|
| Net | GND | +12V | −12V | GND | +100V (+HV) | GND | −100V (−HV) | −100+12V (floating) |

Never reuse a V1 wiring harness on a V2 board. The V2 daisy-chain sockets
also changed (J5/J6: 1 +100V, 2 GND, 3 −100V, 4 −100+12V; J7/J8 are
7-pin: 1 OUT1, 2 GND, 3 OUT2, 4 GND, 5 OUT3, 6 GND, 7 OUT4), so V1 cables
don't fit V2 boards either.

Supply wiring reminders (lessons learned the hard way). The pin numbers below are
**V1 / V2**:
- Every supply connects via its **(+)/(−) output terminals**. The green ⏚
  earth post is NOT an output — using it leaves the rail floating (this
  caused a phantom "TP3 stuck at 6.8 V" reading that looked like a dead U8).
- Triple-output supplies with a ⊥/COM terminal: ⊥ **is** the ground — wire
  ⊥ → board GND, +terminal → +12V (V1 pin 3 / V2 pin 2), −terminal → −12V
  (V1 pin 4 / V2 pin 3). No "flip" needed.
- +HV supply: (+) → +100V (V1 pin 6 / V2 pin 5), (−) → board GND.
- −HV supply: (+) → board GND, (−) → −100V (V1 pin 8 / V2 pin 7).
- Floating 12 V: (−) → −100V (V1 pin 8 / V2 pin 7), (+) → −100+12V (V1 pin 7 /
  V2 pin 8). Must be an isolated output. Third LED confirms it.
- **Jumpers change only with power off and rails discharged** (hot-plugging
  JP4 sparked and nearly killed board #1).

## Bringup log

| Board | Status |
|---|---|
| Board A (original) | Took JP4 hot-plug spark. Output stage suspect (U7/Q1). Parked / parts donor. |
| Board B | Long bringup session: Phases 1–3 passed (TP2 sine, TP3 monitor, TP4 level shift). Phase 4 stalled on level-shifter over-current (TP4 ≈ −14.6 V, suspected RV1 ≈ 0 Ω; never confirmed fixed — swapped out mid-diagnosis). |
| Board C | On −50 V turn-on: −12 rail dragged to −24.9 V, +HV sagged to 30.7 V. Root cause: fried opamp shorting rails. Retired. |
| Board D (current) | Rails behave normally incl. −50 V. Sine does not propagate to output yet ("sine isn't kept") — needs full phased bringup: Q3 leg check, RV1/RV2 ohm-preset, jumper config, then TP2→TP4→TP5 walk. |

Hard-won rules: preset the pots by ohmmeter BEFORE first HV. On pre-V2 boards
(R19/R23 NOT fitted, 4.7k pots): RV2 bottom leg ≈ 1.1 kΩ (gives TP3 ≈ 0.5 V at
±50 V), and RV1 at its MAXIMUM (4.7 kΩ, output then idles near +11 V — safe).
Then, powered, with the DAC held at midscale, turn RV1 DOWN while watching TP5
until TP5 ≈ 0 V (≈ 3.65 kΩ; rule of thumb RV1 ≈ 7.3 kΩ × V_TP3). Gain there ≈ 97.
(An earlier version of this note said "RV1 ≈ 1.0 kΩ" — that is WRONG: LTspice
shows 1.0 kΩ pins the output at the negative rail with ~1 W in R21, and RV1 near
0 Ω is worse — level-shifter over-current that collapses rails and corrupts
everything, incl. TP2.) Keep R19/R23 unfitted: with them fitted the output cannot
be centered with these parts. The output is 100 × V_DAC regardless of rail
voltage, so at ±50 V keep the DAC within about ±0.5 V (≈35% of full scale) or
the output clips at both rails. Check Q3 legs on EVERY board before first −HV.
Verify J9 wiring against the correct revision's table above on every board
swap. On V1 boards, count from the square pad. On V2 boards, read the silkscreen
pin numbers.

Q3 ERRATA STATUS (2026-09-09): the source/drain swap is FIXED in the design
files (hvawg.kicad_sch symbol pin mapping + hvawg.kicad_pcb pad nets, copper
reroute, zone refill; verified — netlist Q3 pin2→levelshift_out / pin3→
Net-(Q3-S), DRC/ERC byte-identical to pre-fix baseline). Boards fabbed from the
fixed files take Q3 with STRAIGHT legs. All boards fabbed earlier (A–D and any
bare spares from the old fab) still REQUIRE the leg-cross. Tell revisions apart
with the 2 mA −HV ramp test. Regenerate gerbers (jlcpcb/ is stale) before any
new order.

## Phase 1 — low-voltage section only

Configuration:

- All HV supplies physically disconnected.
- JP4 open.
- DAC held at its zero-output or midscale code.
- Do not leave both U6 inputs floating as in the original README procedure.
  Either install JP3 and JP6 with DAC and monitor at 0 V, or temporarily pull
  both U6 inputs to ground through approximately 10 kΩ.

Apply ±12 V with separate current limits, initially around 40–60 mA per rail.

Verify:

- +12 V and −12 V at the IC pins;
- TP2 at the expected DC level;
- TP3 approximately 0 V with +HV absent;
- U6 pins 3 and 4 both close to 0 V;
- U4, U6, and U8 remain cool for several minutes;
- no unexpected high-frequency oscillation.

If U4 or U8 heats during this phase, the problem is independent of the HV
potentiometers and points toward rail polarity, soldering, component
orientation, unused-channel oscillation, or damage remaining elsewhere.

## Phase 2 — U8 monitor circuit isolated

Configuration:

- JP6 removed so U8 is not loaded through RV1.
- Temporarily hold U6 pin 4 near ground with about 10 kΩ so U6 does not float.
- Negative HV and output-stage supplies off.

Ramp +HV: +20 V → +60 V → +120 V.

A 2 mA current limit is sufficient for the monitor-only stage after the
hardware corrections.

Expected TP3:

    V_TP3 = V_+HV * R_RV2 / (110k + R_RV2)

For R_RV2 = 1.11 kΩ:

| +HV | Expected TP3 |
|---|---|
| 20 V  | ~0.20 V |
| 60 V  | ~0.60 V |
| 120 V | ~1.20 V |

TP3 and U8 pin 3 should be nearly identical.

Initially adjust RV2 only with power off, then reapply power and remeasure.
A live sweep can be tested later after the fail-safe modifications.

NOTE: A supply current limit alone does not protect an op-amp input from
overvoltage through 110 kΩ: the dangerous fault current may be below 1 mA and
therefore never trip a 5 mA current limit.

## Phase 3 — level shifter without output stage

Configuration:

- JP3 and JP6 installed.
- JP4 open.
- DAC input fixed at 0 V.
- Floating −100+12 V supply still off.

Begin with approximately ±20 V HV rails rather than ±120 V.

Verify:

    V_U6+ ≈ V_U6− ≈ V_DAC

and:

    V_TP4 = V_−HV + (96.4 / R_RV1) * (V_TP3 − V_DAC)

At ±120 V, gain 100, R_RV1 = 225 Ω, V_DAC = 0, and V_TP3 = 1.2 V:

    V_TP4 ≈ −120 + 0.514 = −119.49 V

The corresponding Q3 current is approximately:

    I_Q3 ≈ 1.2 / 225 = 5.3 mA

Use a properly rated differential/isolated probe or a high-voltage DMM for TP4.

Ramp in stages: ±20 V → ±60 V → ±120 V.

Stop immediately if U6 pins 3 and 4 differ substantially, U6 output rails, or
Q3 heats rapidly.

## Phase 4 — output stage at reduced voltage

Power down and discharge the rails, then install JP4.

Connect the floating supply that provides 12 V above the negative rail.
Confirm the voltage between U7 pins 5 and 2 is approximately 12 V; do not
infer this solely from ground-referenced supply displays.

Start at ±20 V with no external load and zero DAC input.

Expected centered R21 current:

    I_R21 = V_+HV / 10k

| Rails  | Centered R21 current |
|---|---|
| ±20 V  | 2 mA |
| ±60 V  | 6 mA |
| ±120 V | 12 mA |

Suitable initial HV current limits:

- 5 mA at ±20 V;
- 12 mA at ±60 V;
- 25 mA at ±120 V for zero or small-signal testing.

For full-scale AC testing, raise the limits cautiously toward roughly
35–40 mA, because the R21 current and Q3 current both rise near the negative
output extreme.

## Phase 5 — calibration

Start with:

- 100 Hz;
- 5–10% full-scale DAC amplitude;
- no external capacitive load.

Then:

1. Measure output peak-to-peak gain.
2. Adjust RV1 slightly to establish gain.
3. Adjust RV2 to center the waveform.
4. Repeat gain and centering once.
5. Increase amplitude.
6. Increase frequency.
7. Add the intended capacitive load last.

Monitor continuously:

- +12 V and −12 V currents;
- positive and negative HV currents;
- TP3;
- U6 pin-3 versus pin-4 voltage;
- TP4;
- U4/U8 temperature;
- Q3, Q1, and R21 temperature.

## Shutdown

Keep ±12 V present until +HV has been ramped to zero, so U8 is never left
with a powered divider and unpowered supply rails. Bring both HV rails to
zero under controlled conditions, discharge them, and only then turn off the
low-voltage rails.

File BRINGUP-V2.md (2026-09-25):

# HVAWG bringup procedure for V2 boards

This is the staged first-article bringup procedure for V2 boards (the safety revision, with R21 laid flat in an on-board heatsink). It keeps Yichen's five-phase structure from the V1 procedure: low voltage only, then the monitor, then the level shifter, then the output stage, then calibration. The numbers are for the V2 parts.

- Expected values come from the netlist of hvawg.kicad_sch (2026-09-24; the component values are unchanged since 2026-09-23) and hand analysis with ideal opamps. They were cross-checked against the LTSpice runs in simulations/v2/, which agree within about 1-3%.
- Locations refer to the component side, with J9's edge at the top. The board is 207 x 58.8mm. The DAC is at the left end, and the output stage (HS1 with R21, then Q1) is at the right end.
- Nothing in this procedure has been run on a V2 board yet. Anything that was derived but not measured is marked "(confirm on first board)".
- When a measurement disagrees with a table, stop and find out why before going on.

Related documents:
- README.md: circuit description.
- V2-SUMMARY.md: what changed in V2, simulation results, and decisions.
- BRINGUP-V1-BOARDS.md: the procedure, lessons and board log for V1 boards A-D.

## 0. Scope and revision check

This document applies only to V2 boards. V1 and V2 boards have different J9, J5/J6 and J7/J8 pinouts, so never use a V1 harness or cable on a V2 board.

| Feature | V2 board (this document) | V1 board (use BRINGUP-V1-BOARDS.md) |
|---|---|---|
| Board | Plain 207 x 58.8mm rectangle; M3 holes at 197 x 48.8mm | 150 x 40mm; holes at 140 x 30mm |
| Bench power input J9 | 3.50mm pluggable terminal block (Phoenix MC 1,5/8-G-3,5, 1844278) on the top edge between J5 and J7, in a 0.5mm edge notch. No tab. | 2.54mm 8-pin header |
| Output bus J7/J8 | 7-pin sockets (OUT1, GND, OUT2, GND, OUT3, GND, OUT4) | 4-pin sockets plus a separate J10 GND socket |
| R21 (10k power resistor) | TO-220 part (Vishay LTO 50) laid flat, ceramic face down, in a Wakefield 272-AB heatsink (HS1, on GND) left of Q1 | Off-board resistor on flying leads |
| Q1 | Alone at the right edge, on its own heatsink bar | Right edge |
| Test points | TP1-TP8 are Keystone loops. TP9-TP12 are bare round SMD pads near Q1/U7. | TP1-TP5 only |
| Q3 | Fitted with straight legs (the S/D fix is in the design files) | Legs crossed by hand |

- Silkscreen version text: boards made from the current files read "HV_AWG v2" at the top left, beside J1. V1 boards read "HV_AWG v1". Still check the features in the table.
- The J9 silkscreen shows pin numbers 1-8, with the net name under each pin. Seen from the component side with J9's edge at the top, pin 1 is the right end and pin 8 the left end. From right to left: 1 GND, 2 +12V, 3 -12V, 4 GND, 5 Vhi, 6 GND, 7 Vlo, 8 Vlo+12.

## 1. Safety first

### 1.1 Hazards on this board

- Voltages: up to ±150V to GND and 300V between the rails. Supplies set to ±50V still put 100V across the board.
- Stored energy: the 4.7uF rail capacitors (C26, C27) hold about 53mJ each at 150V.
- Supply current: the HV supplies can deliver hundreds of mA if the limit is not set (E3612A 0.25A; E3641A about 0.5-0.8A).
- WARNING: THE OUTPUT IS LIVE EVEN WHEN IT "SHOULD" BE AT 0V. Whenever Q1 is off, R21 pulls TP5, TP6, the Q1 tab and the selected J7/J8 output pin up to +HV. Q1 is off in Phases 2 and 3, in Phase 4 before the floating 12V is on, whenever the latched code is on the Q3 cutoff side (including a random power-up code), and after a fault.
- Hot surfaces: HS1 (R21's heatsink, silk "HOT >100C") and R21 on it. At ±150V with the output held near the negative rail and no airflow, the sink can reach about 110-113°C and the R21 element about 141-144°C (estimates, see section 5). HS1 is on GND, so it is not a shock hazard, but it is a burn hazard. Q1 and its bar also get warm.

Live nodes during HV phases:

| Potential | Where it appears |
|---|---|
| +HV | J9-5, J5/J6 pin 1, R12 top, R21 lower pad (pad 2), C26, R24 |
| Output (anywhere between -HV and +HV) | TP5, TP6, Q1 tab (drain), R21 upper pad (pad 1), R31, R32 pad 1 (empty), JP8-JP11, J7/J8 pins 1/3/5/7 |
| About -HV | J9-7, J9-8, J5/J6 pins 3 and 4, C27, R25, TP4, TP9-TP12, both JP4 pins, Q3 tab (drain, silk "TAB ~ -150V"), U7, D4, R17, R22, R18, R28, Q1 gate/source pins, Q3 middle pin, D3 and R3 (both ends; they sit between the J5/J6 -HV traces, left of TP8), C24, C25, R15, the R19/R23 pads |
| Low voltage (near GND) | TP1, TP2, TP3, TP7, TP8, JP3, JP6, RV1, RV2, U2, U3, U4, U6, U8, J1-J4, HS1 (GND, but hot) |

### 1.2 Working rules

- One-hand rule. With HV on, keep one hand off the bench (in a pocket or behind your back). Probe with one hand only.
- Attach clip leads with power off. Clip or solder measurement leads to HV nodes, then power up and read. Do not hunt for pins on a live board.
- WARNING: CHANGE JUMPERS ONLY WITH POWER OFF AND THE RAILS DISCHARGED, AND NEVER PLUG OR UNPLUG J9 LIVE. On V1 board A, hot-plugging JP4 drew a spark and nearly destroyed the board. This also applies to JP8-JP11, the Phase 2 10k clip, the Q1 heatsink bar and the J9 plug (Phoenix: not to be plugged or unplugged under voltage).
- Adjust RV2 only with power off. Adjust RV1 live only with an insulated plastic trim tool, one-handed. RV1 sits at low voltage, but J6, R25, D3/R3 and the J5-J6 -HV traces, about 5.5-8.5mm to its left, are at -HV.
- Set current limits before enabling any output. Use the limits given in each phase. Never run with the limit at max.
- Remove watches and rings. Keep the bench clear of loose wire and metal tools. Do not work alone whenever any HV supply is connected.
- Emergency action: switch the HV supply outputs off (both HV supplies and the floating 12V), then follow section 7.

### 1.3 Bleed-down and discharge

When the HV supplies are ramped to 0, the on-board resistors discharge the rails:

| Rail | Capacitance | Bleed path | Time constant | Time to go from 150V to below 5V |
|---|---|---|---|---|
| +HV | C26 4.7uF | R24 1M in parallel with (R12 110k + R_bottom), about 100k | about 0.5s | about 1.6s |
| -HV | C27 4.7uF | R25 1M (worst case, with Q1/Q3 not conducting) | about 4.7s | about 16s |
| Floating 12V (across C24/C25) | C24 10uF + C25 100nF | R15 1M, plus D3/R3 above about 2.5V | about 10s | D3/R3 pull it below about 2.5V quickly |

Note that the supplies' own output capacitors also discharge into these resistors, so the real discharge can be slower.

Rule: after the supplies read 0V, wait at least 30s. Then, with a DMM, verify all of the following before touching anything or moving a jumper:
- under 5V from J9-5 (+HV) to GND
- under 5V from J9-7 (-HV) to GND
- under 5V from J9-8 (floating rail) to GND and to J9-7

Measure on the J9 plug's screw heads or wire entries (confirm on first board that the plug's screws can be reached with a probe). TP12 (-HV) and TP5 are alternative check points.

### 1.4 Probes and meters

| Rails in use | Highest node-to-GND voltage | Scope probe | DMM |
|---|---|---|---|
| up to ±50V | 50V (100V between rails) | 10x passive probe rated at least 300V (CAT II), set and used at 10x. Never use 1x. | Handheld, battery powered, CAT III 600V |
| above ±50V, up to ±150V | 150V (300V between rails) | 100x HV passive probe rated at least 1kV, or a differential probe rated at least 300V differential and at least 300V common-mode | Handheld, battery powered, CAT III 600V |

- Probe voltage ratings derate with frequency. Check the probe's derating curve before looking at signals in the 100kHz range.
- Use a 1Mohm scope input with DC coupling. Never use 50ohm: a 50ohm input at these voltages destroys the scope input or the terminator.
- WARNING: SCOPE GROUND CLIPS GO ON BOARD GND ONLY. Every channel's ground is the scope chassis, which is earthed. A ground clip on any other node shorts that node to earth.
  - Good GND points: a male header pin inserted into J4 pin 1 or 2 (both GND, in the low voltage area; insert it with power off), J1 pin 1, or J9-1 (the end terminal; never clip onto J9-4 or J9-6, which sit beside +HV).
  - The mounting holes H1-H4 are not connected to GND.
- TP4 and TP9-TP12 sit at about -HV. A probe tip may go on them with the ground clip on GND. Never clip a scope ground to them.
- For the small voltages above -HV (level shifter, Q1 gate/source), use the handheld DMM with COM on the -HV reference (TP12, or a header pin in J6 pin 3 on a standalone board), and put the red lead on the node.
  - The DMM then floats at -HV. Do not touch it or its leads while powered.
  - Attach the COM lead with power off.
  - TP9-TP12 are bare pads. Use a sprung probe tip, or solder a short insulated lead to TP12 with the board unpowered.

### 1.5 Supplies and wiring

- Use only the (+) and (-) output terminals. The green earth post on a bench supply is not an output. Wiring a rail to it leaves the rail floating; on V1 this produced a phantom "TP3 stuck at 6.8V" and "rail reads 0V".
- Triple-output supply (±12V): its COM (ground symbol) terminal is board GND. Wire COM to GND, (+) to +12V and (-) to -12V.
- +HV supply: (+) to +100V, (-) to GND.
- -HV supply: (+) to GND, (-) to -100V. This reverse-biases nothing on the board. C27's + terminal is on GND.
- Floating 12V supply: it must be an isolated output, with (-) to -100V and (+) to -100+12V. Its output-to-earth isolation rating must exceed the -HV setting. Check its manual before going above ±50V (confirm).
- The ±12V pair must never be the channel that supplies the floating 12V, because that channel's COM is GND.
- No earth straps on the -HV and floating supplies. Remove any shorting link between an output terminal and the earth/chassis post on the -HV and floating 12V supplies. Check that each output terminal reads open to the earth post before wiring. The scope and the Pico already earth GND, so a strapped (-) terminal on either supply shorts -HV to GND.

J9 wiring (V2 only). Pin 1 is at the right end.

| J9 pin | Silk label | Net | Connect to |
|---|---|---|---|
| 1 | GND | GND | ±12V supply COM |
| 2 | +12V | +12V | ±12V supply (+) |
| 3 | -12V | -12V | ±12V supply (-) |
| 4 | GND | GND | +HV supply (-) |
| 5 | Vhi | +100V | +HV supply (+) |
| 6 | GND | GND | -HV supply (+) |
| 7 | Vlo | -100V | -HV supply (-) and floating 12V supply (-). Crimp both leads into one twin ferrule (0.5mm^2, e.g. Phoenix AI-TWIN 2x0,5-8 WH); the MC-ST clamp accepts two wires. |
| 8 | Vlo+12 | -100+12V | floating 12V supply (+) |

- Plug: Phoenix MC 1,5/8-ST-3,5, order no. 1840421 (screw clamp). It mates with the 1844278 header on the board. Sources: Mouser 651-1840421, Digi-Key 277-5715-ND, LCSC C3579977. A 3.81mm plug will not mate properly. The MC 1,5/8-ST-3,5 BD:1-8 (1900523) is the same plug with printed numbers; check that its "1" lands on J9 pin 1, the right-hand end.
- Wire: 600V rated hookup wire (e.g. UL1015), because +HV and -HV are 300V apart in the same harness. 24-20 AWG is plenty: the current is under 0.15A even when board 1 feeds a 4-board stack. The clamp takes AWG 28-16; strip 7mm and tighten to 0.22-0.25Nm (Phoenix screwdriver SZS 0,4X2,5 VDE, 1205037).
- Wire and tighten the plug off the board, then plug it in with power off and the rails discharged. Never plug or unplug J9 live. The plug is held by friction only (about 32N), so strain-relieve the harness.
- Rating: the header (1844278) sets it: 250V for overvoltage category II / pollution degree 2 (a lab bench), 160V for III/2. At ±150V rails the largest voltage between neighboring pins is 150V (pins 4-5, 5-6 and 6-7), which is also within the 160V that LCSC lists for the 1840421 plug. Pins 5 and 7 (300V apart) are separated by the grounded pin 6. Do not exceed ±150V rails.
- Label the harness "V2".

Harness verification (every new harness, and every time the harness is rewired). A mirror-image harness is easy to make, because pin 1 is at the right end; it puts HV on the ±12V and GND pins. Plug the harness into J9 with every supply switched off and its leads disconnected from the supplies. Measure the resistance from each supply-end lead to a board point:

| Supply-end lead | Board point | Expected |
|---|---|---|
| ±12V COM | header pin in J4 pin 1  | under 1ohm |
| +12V lead | U4 pin 8 | under 1ohm |
| -12V lead | U4 pin 4 | under 1ohm |
| +HV (+) | C26 + pad / R12 top pad | under 1ohm |
| +HV (-) and -HV (+) | header pin in J4 pin 1  | under 1ohm |
| -HV (-) and floating (-) | TP12 | under 1ohm |
| floating (+) | TP11 | under 1ohm |
| floating (+) | header pin in J4 pin 1  | must not read low (about 2Mohm via R15 + R25, creeping). A mirror-image harness reads under 1ohm here. |

Any other result: stop and rewire.

Power-on order:
1. +12V
2. -12V (apply -12V promptly after +12V; the DAC can heat up with +12V alone)
3. +HV
4. -HV
5. Floating 12V

Power-off order: see section 7. The HV rails and the floating 12V come down first, and ±12V goes off last. U8 must never see a powered HV divider while its own rails are unpowered.

## 2. Equipment

| Item | Requirement | Notes |
|---|---|---|
| ±12V supply | Triple output with COM, 0-12V, current limit adjustable down to about 40mA | Current lab: triple output, with COM used as board GND |
| +HV supply | 0 to target rail. Current limit settable from about 0.5mA up to 35mA. | Current lab: E3612A (bench at +50V; confirm its range before planning above ±50V) |
| -HV supply | Same as +HV | Current lab: E3641A (confirm its range before going above ±50V) |
| Floating 12V supply | Isolated output, 12V, at least 10mA per board. Output-to-earth isolation greater than the -HV magnitude. No output-to-earth strap (section 1.5). | Powers U7 on the -HV rail |
| Two DMMs | Handheld, battery, CAT III 600V, 10Mohm input | One stays on TP5 during Phases 4-5 |
| Oscilloscope | At least 2 channels, 1Mohm inputs | Timebase in ms/div for Pico waveforms |
| Scope probes | 10x rated at least 300V (up to ±50V); 100x HV probe rated at least 1kV, or a rated differential probe (above ±50V) | Section 1.4 |
| Pico / Pico 2 with MicroPython | pico_test_script/pico_dac_test.py, hvawg_driver.py (and main.py for host use later), Thonny or similar REPL | GP3 to J1-2 data, GP2 to J1-3 shift clock, GP5 to J1-4 store clock, GND to J1-1. These are GPIO numbers, not physical pin numbers. |
| Leads | Mini-grabbers, insulated alligator clips, single male header pins (for GND/-HV reference in sockets), a 10kohm resistor with clip leads (Phase 2) | |
| Trim tool | Insulated (plastic) trimmer screwdriver for the 3296Y pots | |
| Mating plug | Phoenix MC 1,5/8-ST-3,5, order no. 1840421 (3.50mm), 600V hookup wire, one twin ferrule for pin 7, wired per section 1.5 | |
| R21/HS1 (fitted at assembly, every board) | Wakefield 272-AB (plain) heatsink; M3x12 and M3x8 pan head screws, one DIN 125 flat washer, one DIN 6797-J internal-tooth washer, two DIN 127 split washers, two M3 nuts; non-silicone grease (Wakefield 126); a lead-forming jig | Section 3.6 |
| Q1 heatsink bar (mandatory above ±50V) | Bar of at most 10°C/W recommended (at most 30°C/W absolute at 40°C ambient), Q1 only, covering board y about 99-111 at the right edge. Sil-Pad K-10 and Keystone 3049 nylon shoulder washer for Q1. M3 hardware. A GND tie wire. Calipers. | Sections 3.6 and 5 |
| Airflow | A fan giving at least 1m/s across HS1's fins if a sustained DC output may sit below about -50V at ±150V (R21 above about 4W; in general below +HV - 200V, so never needed up to about ±100V); recommended for closed stacks at ±150V | Section 5 |
| Temperature | Thermal camera, IR thermometer or thermocouple | |
| Optional | Function generator with high-Z output mode (JP3 injection, Phase 5); insulation tester (Q1 pad and R21-to-sink checks) | |

- Supply ranges: the E3641A tops out at about 60V and the E3612A at 120V (verify against their manuals), so ±150V needs other supplies. The current ±50V bench is within both.

## 3. Pre-power inspection (board unpowered: Phase 0)

### 3.1 Revision and assembly

- V2 confirmed per section 0: J9 block on the top edge in the notch (no tab), 7-pin J7/J8, R21 flat in HS1, "HV_AWG v2".
- Q1 = IRF730, alone at the right edge, right of U7. Its pins from top to bottom are G, D, S, and the tab faces the right edge (by the footprint it stands about 0.4mm past the board edge; a real part varies, see section 3.6). Q3 = IRF9610 in the level shifter area near the bottom edge, tab facing right. Q1 and Q3 are both TO-220, so read the part markings to make sure they are not swapped.
- Q3 legs straight. V2 boards do not take the V1 leg-cross; crossing them reverses Q3.
- R21 (LTO 50) and HS1 fitted per section 3.6. R21 lies ceramic face down in the trough, with its hole on HS1's left-hand hole. Its formed leads go into the two slotted pads left of the sink: upper pad = output, lower pad = +HV. Both screws are torqued before the leads are soldered.
- C26 and C27 polarity (both are 200V polarized electrolytics). C26: + terminal on +100V, - on GND. C27: + terminal on GND, - on -100V. Match each part's polarity mark to the silkscreen.
- R19 and R23 not fitted (the THT vertical footprints: R19 just below JP4's right pin; R23 below R22 in the output stage block, left of TP10). If they are fitted, the output cannot be centered.
- R32/C32 empty. They form a series RC from TP5 to GND (an AC load). Fit them only on purpose, and C32 must then be rated at least 250V.
- V2-only parts present with the right values. The JLC BOM is stale and does not list these, so check them against the schematic. If R29 is 100k (the old value), centering will drift with rail voltage.

  | Part     | Value / type                                                                                                     |
  |----------|------------------------------------------------------------------------------------------------------------------|
  | R26      | 3.3k                                                                                                             |
  | R27      | 820ohm                                                                                                           |
  | R28      | 100k                                                                                                             |
  | R29      | 1M                                                                                                               |
  | R30      | 22k, 2512 (TE CRGP2512F22K, 2W)                                                                                  |
  | R31      | 4.7k, 2512                                                                                                       |
  | D4, D5   | BZT52C12 (check orientation)                                                                                     |
  | RV1, RV2 | 1k 3296Y (not the V1 4.7k)                                                                                       |
  | C24      | 10uF 1206 X7R, 125°C: Samsung CL31B106KAHNNNE (LCSC C14860), not the May BOM X5R CL31A106KBHNNNE (see section 5) |

- JP1 (solder jumper just right of R4/R5, about 4.5mm below U3 pin 1) is open. Bridged, it doubles the DAC current and moves the center code to about 64.
- JP2 (solder jumper just right of R9/R10, above-left of U4) is bridged. Open, it shifts the DAC output up by about 3.75V.
- U3 (DAC0808) orientation matches a working V1 board. The schematic pin numbering is non-standard but unchanged from V1, and V1 boards produced a correct DAC sine. Do not "correct" it.
- J9 header soldered and seated. The plug slides in parallel to the board from the top edge; the edge is notched 0.5mm behind J9 so that the plug seats fully. The wire entries face out, away from the board.
- No solder bridges or flux residue around the HV pads (Q1, Q3, R21, J9, J5/J6, JP4, C26/C27). Clean off flux, which becomes a leakage path at HV.
- Every THT lead trimmed to 2.5mm or less below the board (R21's to about 1.5mm, section 3.6). Stacking needs this (section 6 step 0): an untrimmed Q1 or Q3 lead reaches about 8mm (up to 9.5mm) below the board and, at the recommended spacing, can touch the Q1/Q3 bodies on the board below.
- All removable jumpers (JP3, JP4, JP6, JP8-JP11) are out for sections 3.2 and 3.3.

### 3.2 Resistance checks (power off, jumpers out, rails discharged)

- "Red to black" means the red lead goes on the node that is more positive in operation. In this polarity every FET body diode is reverse biased. Reversed polarity reads lower, because the diodes conduct; that is not a fault.
- Readings creep while the rail capacitors charge from the meter. Read after about 30s.

| Red to black | Designed path | Expected | Stop if |
|---|---|---|---|
| J9-5 (+100V) to J9-1 (GND) | R24 1M in parallel with (R12 110k + R_bottom) | about 100kohm (about 95-105k with R12 at 5%). This is the HV divider, not a fault. | under 50k; about 1-2k means R12 is shorted |
| J9-1 (GND) to J9-7 (-100V) | R25 1M | about 1Mohm (somewhat less from IC leakage) | much less than 1M: C27/R25 fault or a -HV to GND short (this check cannot see Q3; section 4.3 Step A does) |
| J9-5 (+100V) to J9-7 (-100V) | about 100k + 1M | about 1.1Mohm | about 10k: Q1 shorted D-S |
| J9-8 (-100+12V) to J9-7 (-100V) | R15 1M in parallel with D3/R3 and the U7 supply pins | at most 1Mohm, record it | under 1k |
| TP5 to GND | R21 10k to +100V, then the divider (about 100k) | about 110kohm (TP6 about 115k) | 10k or less |
| J9-2 (+12V) to GND | IC supply pins + R1/D1, about 40uF | High and climbing (much more than 10k), record it | under 1k |
| GND to J9-3 (-12V) | IC supply pins + D2/R2, about 40uF | High and climbing, record it | under 1k |
| J9-2 (+12V) to J9-3 (-12V) | Opamp and DAC supply pins | Record it and compare between boards | under 1k (the V1 board C failure: an opamp shorted across the rails) |
| TP1 (+5V) to GND | R7-R10 (10.8k) in parallel with the DAC reference and U2/U3 VCC | at most 10.8kohm. This is naturally the lowest; record it. | under 1k |
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

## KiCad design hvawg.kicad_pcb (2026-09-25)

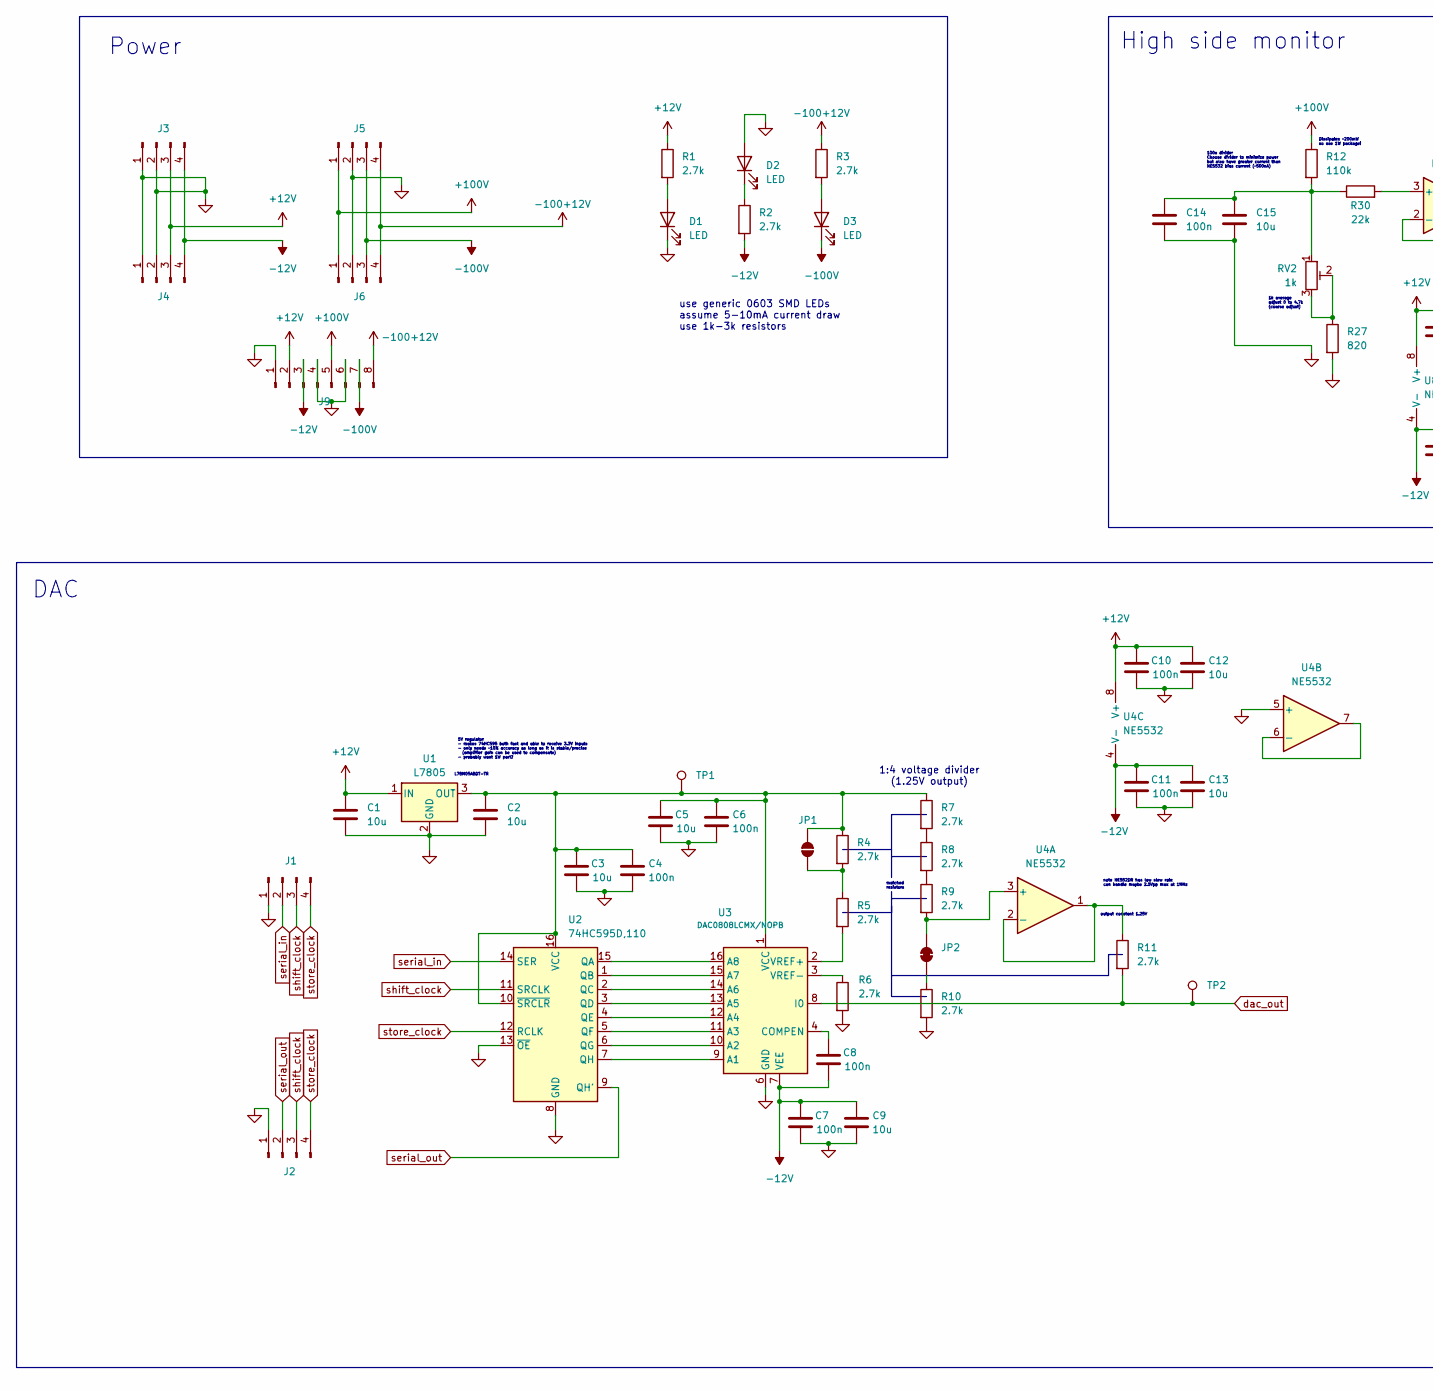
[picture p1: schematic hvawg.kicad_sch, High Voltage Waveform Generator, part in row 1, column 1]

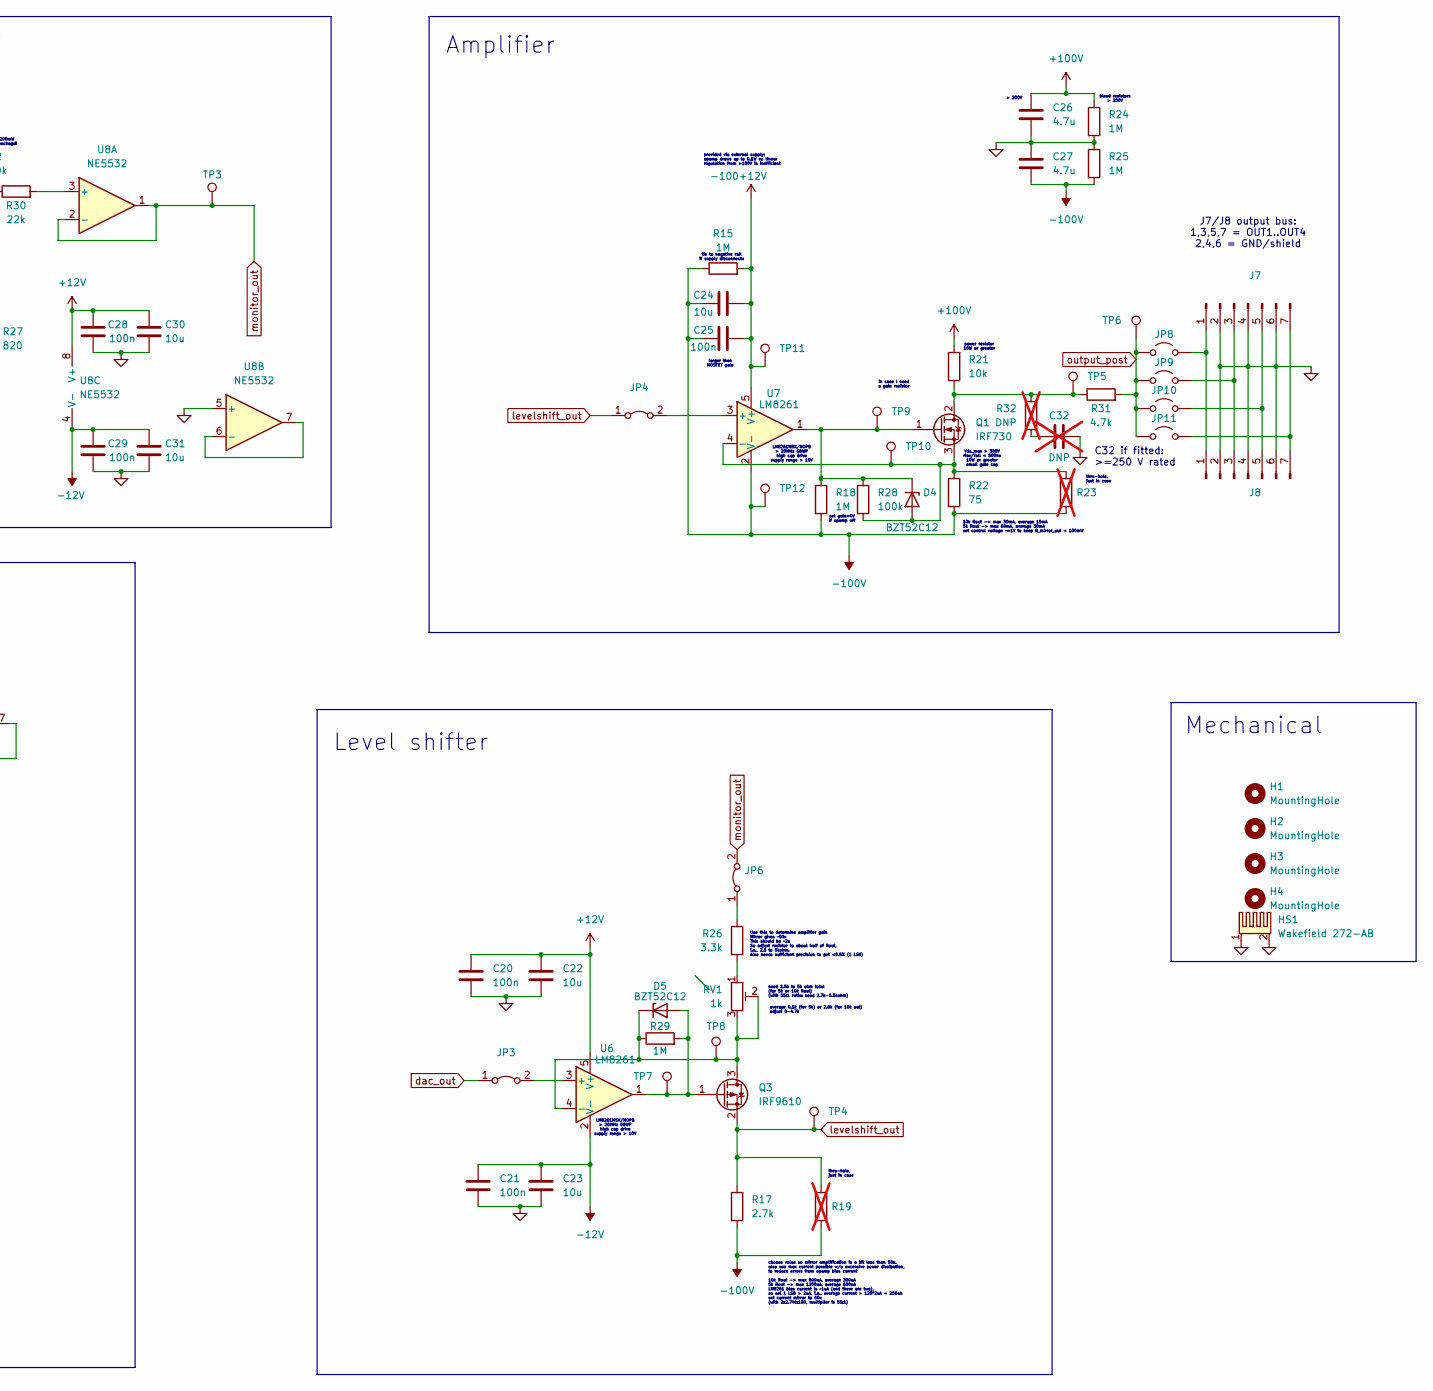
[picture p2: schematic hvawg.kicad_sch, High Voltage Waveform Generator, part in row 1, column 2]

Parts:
C1, C2, C3, C5, C9, C12, C13, C15, C22, C23, C30, C31: 10u; C_1206_3216Metric
C4, C6, C7, C8, C10, C11, C14, C20, C21, C25, C28, C29: 100n; C_0603_1608Metric
C24: 10u; C_1206_3216Metric; MPN CL31B106KAHNNNE
C26, C27: 4.7u; CP_Elec_8x10.5
C32: DNP; C_1206_3216Metric; not fitted
D1, D2, D3: LED; LED_0603_1608Metric
D4, D5: BZT52C12; D_SOD-123
H1, H2, H3, H4: MountingHole; MountingHole_3.2mm_M3_Pad
HS1: Wakefield 272-AB; Heatsink_Wakefield_272-AB; MPN 272-AB
J1, J3, J5: Conn_01x04_Pin; PinSocket_1x04_P2.54mm_Horizontal_flipped
J2, J4, J6: Conn_01x04_Pin; PinSocket_1x04_P2.54mm_Horizontal
J7: Conn_01x07_Pin; PinSocket_1x07_P2.54mm_Horizontal_flipped
J8: Conn_01x07_Pin; PinSocket_1x07_P2.54mm_Horizontal
J9: Conn_01x08_Pin; PhoenixContact_MC_1,5_8-G-3.5_1x08_P3.50mm_Horizontal_EdgeN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; MPN 1844278
JP1: SolderJumper_2_Open; SolderJumper-2_P1.3mm_Open_RoundedPad1.0x1.5mm
JP2: SolderJumper_2_Bridged; SolderJumper-2_P1.3mm_Bridged_RoundedPad1.0x1.5mm
JP3, JP4, JP6: Jumper_2_Bridged; PinHeader_1x02_P2.54mm_Vertical
JP8, JP9, JP10, JP11: Jumper_2_Open; PinHeader_1x02_P2.54mm_Vertical
Q1: IRF730; TO-220-3_Vertical_HV
Q3: IRF9610; TO-220-3_Vertical_HV
R1, R2, R3, R4, R5, R6, R7, R8, R9, R10, R11, R17: 2.7k; R_0402_1005Metric
R12: 110k; R_2010_5025Metric
R15, R18, R24, R25: 1M; R_1206_3216Metric
R19, R23: 100; R_Axial_DIN0207_L6.3mm_D2.5mm_P2.54mm_Vertical; not fitted
R21: 10k; TO-220-2_Horizontal_LTO50; MPN LTO050F10001JTE3
R22: 75; R_2010_5025Metric
R26: 3.3k; R_0402_1005Metric
R27: 820; R_0402_1005Metric
R28: 100k; R_0402_1005Metric
R29: 1M; R_0402_1005Metric
R30: 22k; R_2512_6332Metric; MPN CRGP2512F22K
R31: 4.7k; R_2512_6332Metric
R32: DNP; R_1206_3216Metric; not fitted
RV1, RV2: 1k; Potentiometer_Bourns_3296Y_Vertical
TP1, TP2, TP3, TP4, TP5, TP6, TP7, TP8: TestPoint; TestPoint_Keystone_5005-5009_Compact
TP9, TP10, TP11, TP12: TestPoint; TestPoint_Pad_D1.5mm
U1: L7805; TO-252-2
U2: 74HC595D,110; SOIC-16_3.9x9.9mm_P1.27mm
U3: DAC0808LCMX/NOPB; SOIC-16_3.9x9.9mm_P1.27mm
U4, U8: NE5532; SOIC-8_3.9x4.9mm_P1.27mm
U6, U7: LM8261; SOT-23-5

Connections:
+12V: C1.1, C10.1, C12.1, C20.1, C22.1, C28.1, C30.1, J3.3, J4.3, J9.2, R1.1, U1.1 (IN), U4.8 (V+), U6.5 (V+), U8.8 (V+)
+100V: C26.1, J5.1, J6.1, J9.5, R12.1, R21.2, R24.1
-12V: C7.1, C8.2, C9.1, C11.1, C13.1, C21.1, C23.1, C29.1, C31.1, J3.4, J4.4, J9.3, R2.2, U3.7 (VEE), U4.4 (V-), U6.2 (V-), U8.4 (V-)
-100+12V: C24.2, C25.2, J5.4, J6.4, J9.8, R3.1, R15.2, TP11.1, U7.5 (V+)
-100V: C24.1, C25.1, C27.2, D3.1 (K), J5.3, J6.3, J9.7, R15.1, R17.2, R18.2, R19.2, R22.2, R23.1, R25.2, TP12.1, U7.2 (V-)
GND: C1.2, C2.2, C3.2, C4.2, C5.2, C6.2, C7.2, C9.2, C10.2, C11.2, C12.2, C13.2, C14.2, C15.2, C20.2, C21.2, C22.2, C23.2, C26.2, C27.1, C28.2, C29.2, C30.2, C31.2, C32.2, D1.1 (K), D2.2 (A), HS1.1, HS1.2, J1.1, J2.1, J3.1, J3.2, J4.1, J4.2, J5.2, J6.2, J7.2, J7.4, J7.6, J8.2, J8.4, J8.6, J9.1, J9.4, J9.6, R6.2, R10.2, R24.2, R25.1, R27.2, U1.2 (GND), U2.8 (GND), U2.13 (~OE), U3.6 (GND), U4.5 (+), U8.5 (+)
unnamed: C14.1, C15.1, R12.2, R30.1, RV2.1
unnamed: C32.1, R32.2
unnamed: D1.2 (A), R1.2
unnamed: D2.1 (K), R2.1
unnamed: D3.2 (A), R3.2
unnamed: D4.2 (A), Q1.3 (S), R22.1, R23.2, R28.2, TP10.1, U7.4 (-)
unnamed: D4.1 (K), Q1.1 (G), R18.1, R28.1, TP9.1, U7.1
unnamed: D5.2 (A), Q3.1 (G), R29.2, TP7.1, U6.1
unnamed: D5.1 (K), Q3.3 (S), R29.1, RV1.2, RV1.3, TP8.1, U6.4 (-)
unnamed: J7.1, J8.1, JP8.2 (B)
unnamed: J7.3, J8.3, JP9.2 (B)
unnamed: J7.5, J8.5, JP10.2 (B)
unnamed: J7.7, J8.7, JP11.2 (B)
unnamed: JP1.1 (A), R4.2, R5.1
unnamed: C2.1, C3.1, C4.1, C5.1, C6.1, JP1.2 (B), R4.1, R7.1, TP1.1, U1.3 (OUT), U2.10 (~SRCLR), U2.16 (VCC), U3.1 (VCC)
unnamed: JP2.1 (A), R10.1
unnamed: JP2.2 (B), R9.2, U4.3 (+)
unnamed: JP3.2 (B), U6.3 (+)
unnamed: JP4.2 (B), U7.3 (+)
unnamed: JP6.1 (A), R26.1
unnamed: Q1.2 (D), R21.1, R31.1, R32.1, TP5.1
unnamed: R7.2, R8.1
unnamed: R8.2, R9.1
unnamed: R26.2, RV1.1
unnamed: R27.1, RV2.2, RV2.3
unnamed: U2.15 (QA), U3.16 (A8)
unnamed: U2.1 (QB), U3.15 (A7)
unnamed: U2.2 (QC), U3.14 (A6)
unnamed: U2.3 (QD), U3.13 (A5)
unnamed: U2.4 (QE), U3.12 (A4)
unnamed: U2.5 (QF), U3.11 (A3)
unnamed: U2.6 (QG), U3.10 (A2)
unnamed: U2.7 (QH), U3.9 (A1)
unnamed: C8.1, U3.4 (COMPEN)
unnamed: R5.2, U3.2 (VREF+)
unnamed: R6.1, U3.3 (VREF-)
unnamed: R11.1, U4.1, U4.2 (-)
unnamed: U4.6 (-), U4.7
unnamed: R30.2, U8.3 (+)
unnamed: U8.6 (-), U8.7
dac_out: JP3.1 (A), R11.2, TP2.1, U3.8 (I0)
levelshift_out: JP4.1 (A), Q3.2 (D), R17.1, R19.1, TP4.1
monitor_out: JP6.2 (B), TP3.1, U8.1, U8.2 (-)
output_post: JP8.1 (A), JP9.1 (A), JP10.1 (A), JP11.1 (A), R31.2, TP6.1
serial_in: J1.2, U2.14 (SER)
serial_out: J2.2, U2.9 (QH')
shift_clock: J1.3, J2.3, U2.11 (SRCLK)
store_clock: J1.4, J2.4, U2.12 (RCLK)

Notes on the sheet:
Vds_max > 300V rise/fall < 500ns 10W or greater small gate cap
Level shifter
LM8261M5X/NOPB > 20MHz GBWP high cap drive supply range > 10V
100x divider Choose divider to minimize power but also have greater current than NE5532 bias current (~500nA)
provided via external supply; opamp draws up to 0.1W so linear regulation from >100V is inefficient
average 0.1k (for 5k) or 2.8k (for 10k out) adjust 0-4.7k
1k average adjust 0 to 4.7k (coarse adjust)
use generic 0603 SMD LEDs assume 5-10mA current draw use 1k-3k resistors
L78M05ABDT-TR
Use this to determine amplifier gain Mirror gives ~50x This should be ~2x So adjust resistor to about half of Rout, i.e., 2.5 to 5kohm. Also needs sufficient precision to get <0.5% (1 LSB)
Power
thru-hole, just in case
note NE552DR has low slew rate can handle maybe 2.5Vpp max at 1MHz
in case I need a gate resistor
1:4 voltage divider (1.25V output)
5V regulator - makes 74HC595 both fast and able to receive 3.3V inputs - only needs ~10% accuracy as long as it is stable/precise (amplifier gain can be used to compensate) - probably want 1W part?
> 200V
J7/J8 output bus: 1,3,5,7 = OUT1..OUT4 2,4,6 = GND/shield
larger than MOSFET gate
power resistor 10W or greater
set gate=0V if opamp off
bleed resistors > 200V
DAC
Dissipates ~200mW so use 1W package!
High side monitor
choose value so mirror amplification is a bit less than 50x. also use max current possible w/o excessive power dissipation, to reduce errors from opamp bias current 10k Rout -> max 600uA, average 300uA 5k Rout -> max 1200uA, average 600uA LM8261 bias current is ~1uA (and there are two), so set 1 LS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
output constant 1.25V
Mechanical
matched resistors
10k Rout -> max 30mA, average 15mA 5k Rout -> max 60mA, average 30mA set control voltage ~=1V to keep R_mirror_out < 100mW
tie to negative rail if supply disconnects
Amplifier
need 2.5k to 5k ohm total (for 5k or 10k Rout) (with 55:1 ratio: need 2.7k-5.5kohm)
C32 if fitted: >=250 V rated

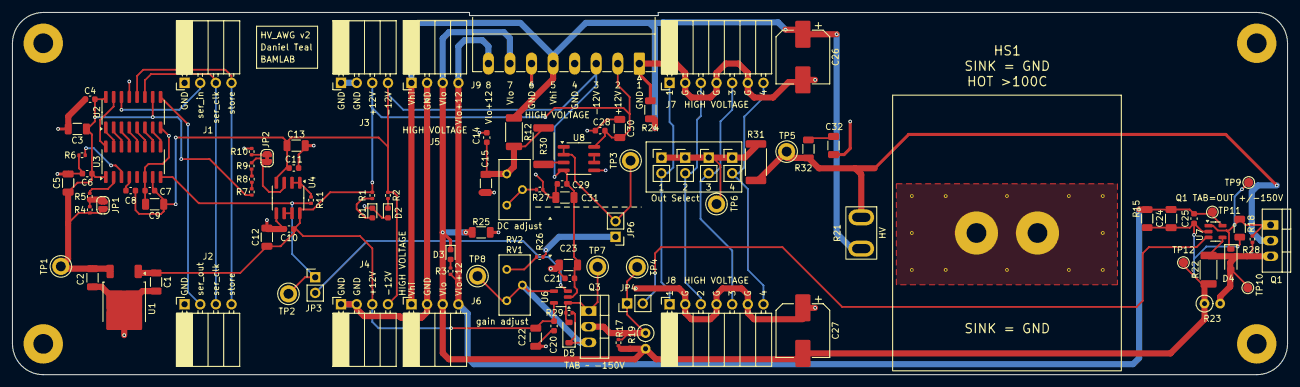
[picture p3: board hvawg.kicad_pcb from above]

Board: 2 copper layers, 207.0 x 58.8 mm, 107 parts (0 on the bottom side), 54 nets.

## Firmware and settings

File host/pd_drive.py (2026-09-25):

"""Host-side PD controller for the HVAWG 4-channel HV driver.

Computes a desired output VOLTAGE per channel from a measured height/position
and streams setpoints to the Pico (which clamps, calibrates, and drives the HV).

Run on the PC. The Pico runs pico_test_script/main.py.
Wire your sensor read into read_heights().
"""

import serial
import time

PORT = "COM5"          # <-- set to your Pico's serial port
DT = 0.005             # control period (s). 5ms = 200Hz. USB-CDC jitter dominates;
                       # for a true deterministic kHz loop, move PD onto the Pico.
N = 4


class PD:
    """PD with a low-passed derivative (raw D on a noisy sensor is unusable)."""
    def __init__(self, kp, kd, dt, d_alpha=0.2):
        self.kp, self.kd, self.dt, self.a = kp, kd, dt, d_alpha
        self.prev_e = None
        self.df = 0.0

    def step(self, setpoint, measured):
        e = setpoint - measured
        d = 0.0 if self.prev_e is None else (e - self.prev_e) / self.dt
        self.df = self.a * d + (1 - self.a) * self.df    # filter the D term
        self.prev_e = e
        return self.kp * e + self.kd * self.df           # -> desired VOLTS


def read_heights():
    """Return [h0, h1, h2, h3] from your sensor. STUB -- wire this up."""
    return [0.0] * N


def main():
    pico = serial.Serial(PORT, 115200, timeout=0.01)   # baud irrelevant for USB-CDC
    pd = [PD(kp=2.0, kd=0.05, dt=DT) for _ in range(N)]
    setpoint = [0.0] * N                                # target heights

    def send(volts):
        pico.write(("%.3f,%.3f,%.3f,%.3f\n" % tuple(volts)).encode())

    next_t = time.perf_counter()
    try:
        while True:
            next_t += DT
            h = read_heights()
            v = [pd[ch].step(setpoint[ch], h[ch]) for ch in range(N)]   # volts
            send(v)                                     # Pico clamps to +/-V_MAX
            # (optional) read back "ok,c0,c1,c2,c3" for logging:
            # print(pico.readline().decode().strip())
            time.sleep(max(0.0, next_t - time.perf_counter()))
    except KeyboardInterrupt:
        pico.write(b"z\n")                              # panic stop on exit
        pico.close()


if __name__ == "__main__":
    main()

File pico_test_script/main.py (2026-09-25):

# Pico firmware: watchdog'd 4-channel DAC server (Option C).
# The HOST computes the PD control and sends 4 setpoint voltages per update;
# the Pico clamps, calibrates, shifts all 4 bytes, latches once, and parks the
# outputs at 0V if the host goes silent.
#
# Protocol over USB serial:
#   host -> Pico : "v0,v1,v2,v3\n"  (volts; out-of-range is clamped, not rejected)
#                  "z\n"            (panic stop -> all 0V)
#   Pico -> host : "ok,c0,c1,c2,c3\n"  (codes actually latched)  or  "err,..."

import sys, select, time
from hvawg_driver import HVAWG

hv = HVAWG(use_spi=True)
hv.all_zero()

poll = select.poll()
poll.register(sys.stdin, select.POLLIN)
line = ""

def handle(cmd):
    global line
    cmd = cmd.strip()
    if cmd == "z":                          # panic stop
        hv.all_zero(); hv.feed()
        print("ok,stop"); return
    parts = cmd.split(",")
    if len(parts) != 4:
        print("err,malformed"); return
    try:
        v = [float(p) for p in parts]
    except ValueError:
        print("err,nan"); return
    codes = hv.set_channels(v)              # clamp + cal + 4-byte + single latch
    hv.feed()                              # feed watchdog ONLY on a valid setpoint
    print("ok,%d,%d,%d,%d" % tuple(codes))

while True:
    # Drain ALL characters available this tick (not one-per-poll -> no throttle).
    while poll.poll(0):                     # 0ms = non-blocking: any char ready?
        ch = sys.stdin.read(1)
        if ch == "\n":
            handle(line); line = ""
        elif ch:
            line += ch
    if hv.expired():                        # host silent -> FAILSAFE (do NOT feed)
        hv.all_zero()
    time.sleep_ms(1)                        # ~1 kHz service tick

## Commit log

2026-09-09 Fix Q3 source/drain swap in design files; regenerate gerbers
    [hvawg.kicad_pcb, hvawg.kicad_sch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]
2026-09-25 pico tests added
2026-09-25 new board
    [hvawg.kicad_pcb, hvawg.kicad_sch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]
2026-10-10 all of the V2 changes: schematic changes, labels, regenerated gerbers, etc
2026-10-10 updated pico tests
